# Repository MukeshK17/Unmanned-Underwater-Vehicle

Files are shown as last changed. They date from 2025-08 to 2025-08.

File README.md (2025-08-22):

# Unmanned-Underwater-Vehicle

This repository is a part of project course at Indian Institute of Technology Gandhinagar on prototyping of Unmanned Underwater vehicle form scratch.

Team Members:
- Kushagra Shahi
- Mukesh Dewangan
- Vivek Kumar
- USNV Mohana Krishna
- Kunala Thrisha
- Atharva Prasad Suryarao

Thanks to our Professors Atul Bhargav, Ravi Sastri Ayyagari and Vinod Narayanan for their support and insights.
---

📖 Project Overview
This project focused on building a prototype of an Unmanned Underwater Vehicle (UUV). The prototype was designed using a PVC body, acrylic flanges, and rubber/PTFE gaskets to ensure watertight sealing. A ballast system was incorporated for vertical motion control, allowing adjustment of buoyancy during operation.
The key objective was to develop a low-cost, testable underwater platform while addressing critical design challenges such as sealing, structural integrity, and operational safety.

⚙️ Features & Components
- Hull: PVC pipe structure
- Flanges: Acrylic, laser-cut, modified with 12 bolt holes (instead of 8) for improved sealing
- Gasket: PTFE gasket chosen for elasticity, water resistance, and reusability
- Ballast System: Provides up to 0.5 kg intake for buoyancy control
- Propulsion: Propeller shaft with bearing support

🔧 Repairs & Improvements
- Propeller Shaft Bearing: Needs replacement due to wear and water leakage.
- Front-End Flange: Damaged acrylic flange requires replacement with a new one of the same dimensions.

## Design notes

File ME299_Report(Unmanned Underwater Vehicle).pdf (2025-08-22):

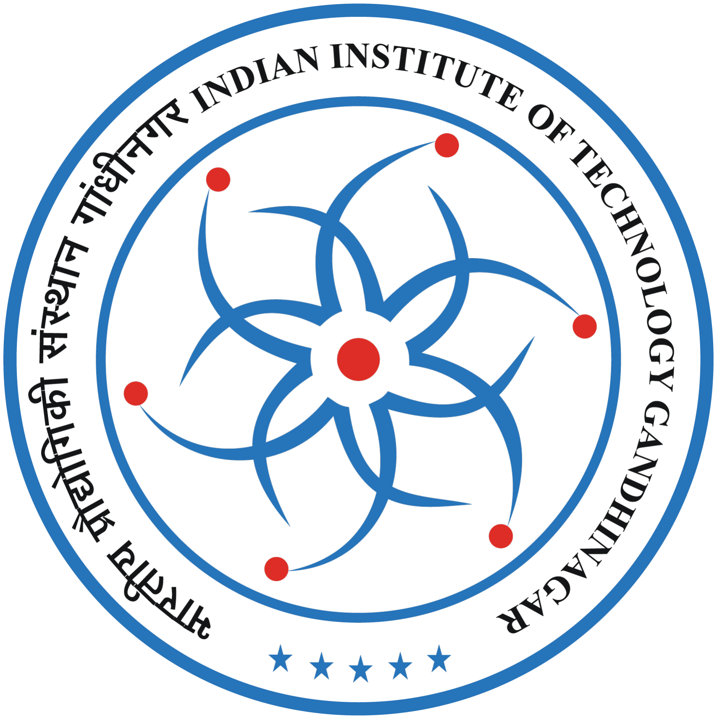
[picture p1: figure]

Indian Institute of Technology

Gandhinagar

## ME 299: Project Course

## Unmanned Underwater Vehicle

Structure Team

Vivek Kumar | 23110361
USNV Mohana Krishna | 23110345
Mukesh Dewangan | 23110211
Kushagra Shahi | 23110183
Kunala Thrisha | 23110182
Atharva Prasad Suryarao 23110051

Professor :
Prof. Atul Bhargav
Prof. Ravi Sastri Ayyagari Prof. Vinod Narayanan

Contents

## Contents

1 Introduction | 2
2 Operating Instructions | 2
3 Gasket Design and Selection | 3
4 Flange Design and Selection | 4
5 Design & Drawings | 5
6 Repairs and Improvements | 6
ME 299 | 1

2 Operating Instructions

## 1 Introduction

This project focused on building a prototype of an Unmanned Underwater Vehicle (UUV). The main body was made from a PVC pipe, with acrylic flanges and rubber gaskets used to create watertight seals at the ends. Since the electronics had to be accessible, both flanges were designed with a removable cover. To enable movement in the vertical direction, a ballast system was added, allowing the prototype to control its buoyancy and adjust depth in water.

## 2 Operating Instructions

- Always operate the submarine in controlled water bodies (test tanks, pools, or calm water).
- Do not expose electrical systems to water without proper sealing.
- Ensure all seals, flanges, and propeller fittings are checked before every use.
- Do not overload the submarine with additional weight beyond the design limit.
- Keep hands and clothing clear of the propeller while powered.
- Inspect the submarine for visible damage or loose fittings.
- Confirm that the propeller shaft rotates freely without obstruction.
- Ensure watertight seals are intact before deployment.
- Place the submarine gently into the water.

Buoyancy and Weight Limitations

- The submarine achieves neutral buoyancy when its total weight (vessel + components + payloads) equals 24.5 kg.
- Safe Operating Range: The submarine must weigh between 24.0 kg and 24.5 kg prior to deployment. If the weight exceeds 24.5 kg, the vessel will sink.
- The ballast system can intake up to 0.5 kg of water, enabling fine adjustments to buoyancy within the safe operating range.

Always verify the total weight of the submarine before operation to ensure it falls within this specified range.

3 Gasket Design and Selection

## 3 Gasket Design and Selection

### 3.1 Sealing Requirements

- Issue: Preventing water leakage at the ends of the submarine prototype was critical. The design employed a hollow flange attached to the submarine body and a blind flange as a removable cover. Both were made of acrylic and joined using 12 bolts. Since the blind flange also served as the primary access point for electronics, it required frequent removal and reattachment. Consequently, the gasket material had to provide reliable sealing while also being reusable.

### 3.2 Initial Attempt – Thermal Gasket

- Issue: A thermal gasket was initially tested. However, its stiffness and lack of compressibility resulted in uneven clamping when the bolts were tightened sequentially. This caused stress concentrations in the brittle acrylic flanges, leading to cracking.
- Action Taken: The thermal gasket was rejected as unsuitable due to its inability to distribute stresses evenly and its tendency to damage the flange material.

### 3.3 Final Selection – PTFE Gasket

PTFE (Polytetrafluoroethylene) was identified as an ideal gasket material for the following reasons:

- Lightweight and elastic, providing adequate compressibility.
- Highly resistant to water, ensuring long-term sealing performance.
- Easy to fabricate using simple tools (e.g., thermocol cutter).
- Reusable, retaining its sealing properties after multiple installations.

### 3.4 Fabrication and Installation

- The PTFE sheet was cut to match the hollow flange geometry.
- Bolt holes were pierced slightly smaller than the bolt diameter. This allowed the material to compress tightly around the bolts, eliminating potential leakage through bolt clearances.
- The gasket was installed between the blind and hollow flanges, providing uniform stress distribution and protecting the acrylic from cracking.

### 3.5 Performance Outcome

The PTFE gasket performed effectively, ensuring a watertight seal while enabling repeated removal and reinstallation without loss of performance. It offered a practical and reliable solution for both leakage prevention and maintenance access.

4 Flange Design and Selection

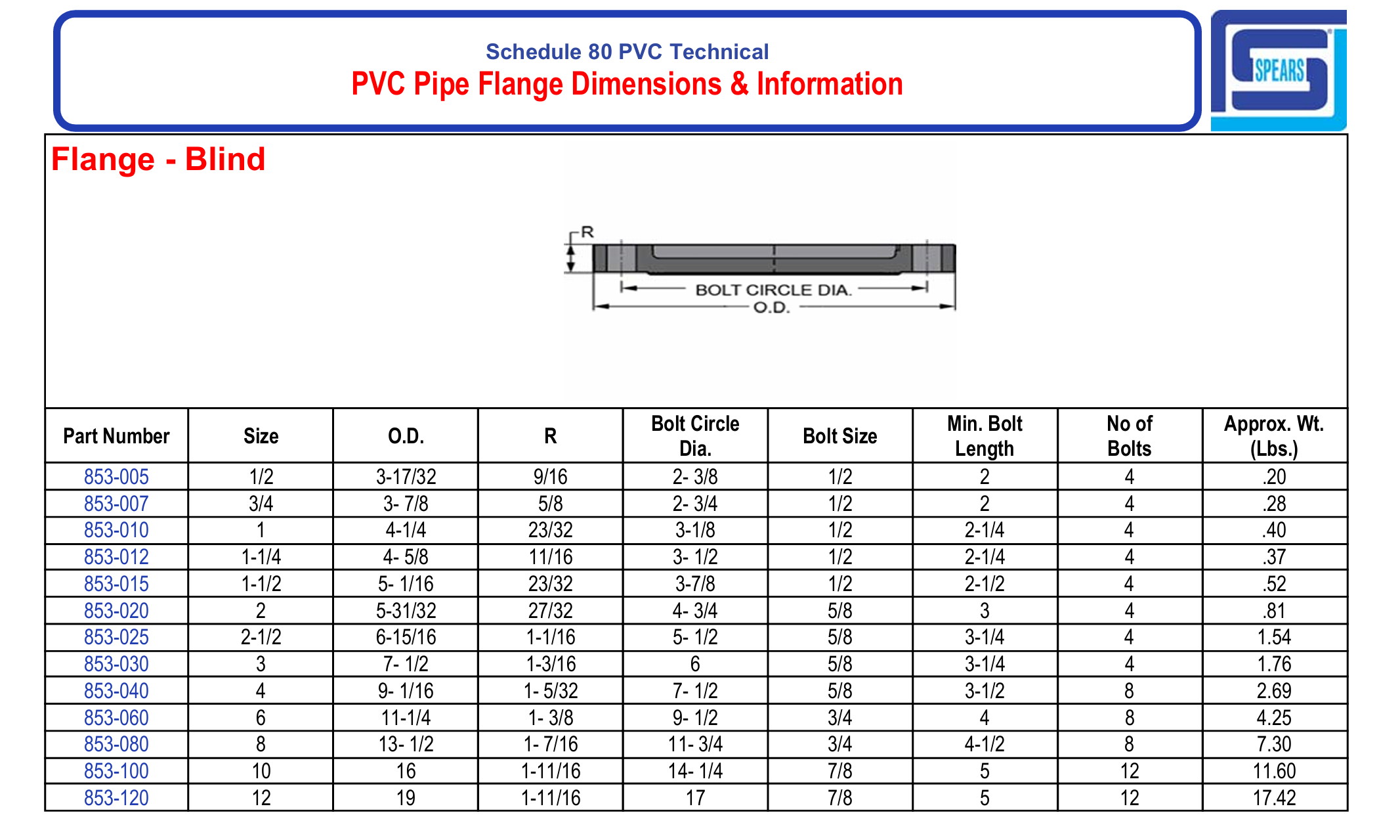
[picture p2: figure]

Figure 1: ASME Blind Flanges

Reference:
https://parts.spearsmfg.com/sourcebook/SCH80TECH_80_FLANGES_T.pdf

## 4 Flange Design and Selection

### 4.1 Sealing Requirements

- Issue: The ends of the prototype needed to be sealed reliably to prevent water leakage while still allowing periodic access to the internal electronics. A flange system was required to provide both watertight integrity and mechanical strength.

### 4.2 Material Selection – Acrylic Sheets

- Availability: Readily available and easy to procure (sourced from Maker Bhavan).
- Manufacturability: Can be precisely cut using a laser cutter, ensuring accurate dimensions and bolt-hole alignment.
- Weight: Lightweight and easy to handle during assembly.
- Pressure Resistance: Adequate to withstand hydrostatic pressure up to a water depth of 6 feet, which matched the operating conditions of the prototype.
- Limitation: Acrylic is brittle and prone to cracking if bolts are overtightened, leading to material wastage and sealing failure.

5 Design & Drawings

### 4.3 Bolt and Hole Specifications

- Issue: Using non-standard bolt sizes could compromise the seal and result in leakage, which would damage onboard electrical systems.
- Action Taken: The flange dimensions and bolt patterns were referenced from ASME standards (Size 8) to ensure proper fitment and sealing performance.

### 4.4 Design Modification

- Issue: Standard size 8 flanges typically use 8 bolt holes, which may not provide sufficient sealing security in a prototype made from brittle acrylic.
- Action Taken: Following advice from an industry expert, the design was modified to incorporate 12 bolt holes instead of 8. This increased the uniformity of clamping pressure, reduced the chance of leakage, and minimized the risk of localized stresses causing cracks.

### 4.5 Performance Outcome

The acrylic flanges, when combined with the modified bolt-hole arrangement, provided a secure and repeatable sealing method for the prototype. Although material brittleness remained a limitation, proper bolt tightening and the use of a compressible gasket reduced the likelihood of failure and ensured watertight operation.

## 5 Design & Drawings

(All dimensions in mm)

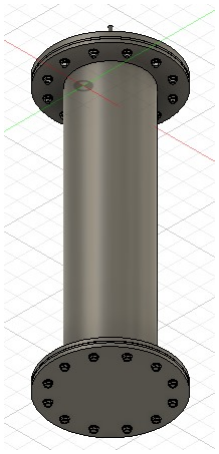
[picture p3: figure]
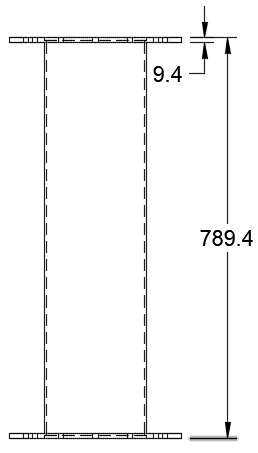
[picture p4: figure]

Side View of the Vehicle | Isometric View

6 Repairs and Improvements

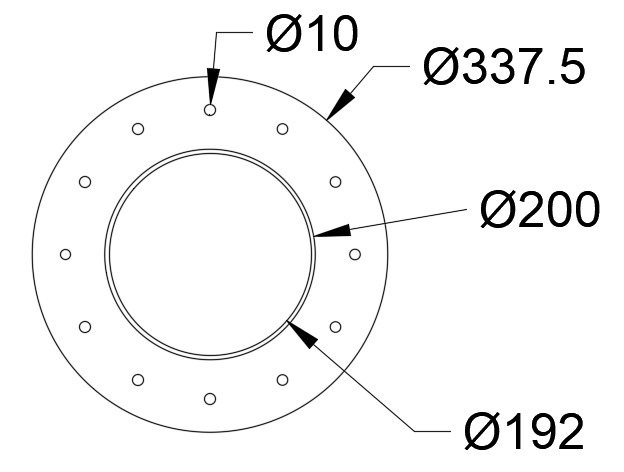
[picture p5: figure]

Top View of the Vehicle (Flanges)

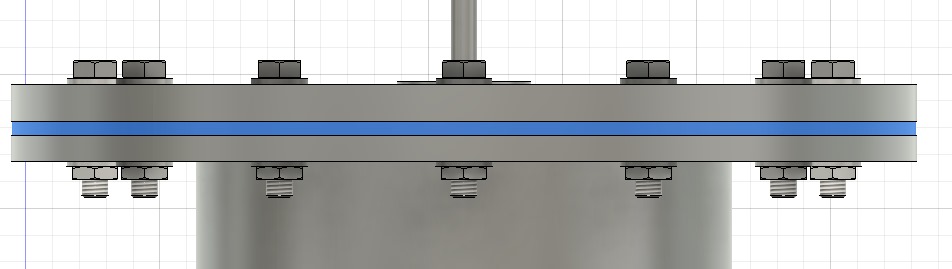
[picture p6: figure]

5mm Gasket

## 6 Repairs and Improvements

1. Propeller Shaft Bearing
- Issue: The ball bearing connected to the propeller shaft has developed play due to repeated usage. This has resulted in water leakage through the bearing.
- Action Required: Replace the existing bearing with a new one. Ensure the new bearing is properly aligned and securely seated. Apply an appropriate sealant to prevent water ingress from the propeller end of the submarine.
2. Front-End Flange
- Issue: The hollow front-end flange attached to the submarine body has sustained damage.
- Action Required: Remove the damaged flange and install a new hollow flange of the same dimensions. Verify that the new flange is securely fitted and sealed to maintain structural integrity and watertight performance.

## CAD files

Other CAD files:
Unmanned Underwater vehicle CAD file.f3z
